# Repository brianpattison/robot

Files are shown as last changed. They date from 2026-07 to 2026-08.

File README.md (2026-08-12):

# Robot

An embodied Codex companion project: a small indoor robot body that can listen, talk, look around, and move safely through the house.

The design goal is pet-like presence without overcomplicating the first build. The MVP is a compact wheeled robot with a camera head, microphone array, speaker, LEDs, bumpers, conservative autonomy, and a physical E-stop. Tiny body, serious safety shoes.

## Current Status

The current direction is the **v2 printed-only hybrid-material body** (decision
log D025-D035): 40 installed functional pieces, four spare washers, and one
optional cosmetic lid skin on 13 zero-support plates, with one screw size and
one insert size.

> **Prototype assembly preview — do not use for powered motion.** The tracked v2
> 3MF and builder's book are geometry and dry-assembly artifacts. The head/neck
> load paths are fully modeled and kinematically validated. A versioned Pi 5
> appliance installer/`robotd` with its localhost supervision dashboard, framed
> UART contract, portable Pico safety core, deliberately fail-stopped Pico
> target, nominal harness traveler, and executable commissioning gate now ship,
> and the book's closing chapter walks the builder through the bench simulator,
> the Pi install, and the resident copilot's seat. Exact-part fit, production motor
> outputs, exact harness terminals/lengths, released fuse values, loaded
> wear/current testing, and signed physical evidence remain open.

- **Versioned v2 Builder Release Index:** [`docs/builder-release-v2.md`](docs/builder-release-v2.md)
- **The Builder's Book (v2 prototype preview):** [`output/pdf/codex_robot_body_v2_assembly_guide.pdf`](output/pdf/codex_robot_body_v2_assembly_guide.pdf)
- **The interactive Builder's Site (same content, live progress):** build with
  [`docs/generate_guide_site_v2.py`](docs/generate_guide_site_v2.py) → `output/site/index.html`
  (offline-first; tracks shop/print/build progress in your browser)
- v2 Bambu Studio project: [`cad/bambu/codex_robot_body_v2_p1s.3mf`](cad/bambu/codex_robot_body_v2_p1s.3mf)
- v2 qualification-proof project: [`cad/bambu/codex_robot_body_v2_proofs_p1s.3mf`](cad/bambu/codex_robot_body_v2_proofs_p1s.3mf)
- v2 book generator: [`docs/generate_assembly_guide_v2.py`](docs/generate_assembly_guide_v2.py)
- bench protocol: [`docs/body-protocol-v1.md`](docs/body-protocol-v1.md)
- Pi runtime/appliance: [`software/robotd/`](software/robotd/), [`software/appliance/`](software/appliance/), and the [provisioning guide](docs/pi-appliance-provisioning.md)
- localhost supervision dashboard: [`software/dashboard/`](software/dashboard/)
- Pico safety-core baseline: [`firmware/pico2-safety/`](firmware/pico2-safety/)
- harness traveler and release gate: [`harness/`](harness/)
- executable commissioning package: [`commissioning/`](commissioning/)

Visible replaceable panels and diffusers now use configurable PLA theme slots;
functional PETG is restricted to white structure, black wear parts, and red
service retainers. The shell and head remain white-PETG fallbacks until the
exact candidate PLA family passes the recorded physical gates (D034).

Everything below the book is the engineering paper trail and the current source
of truth for open release gates. Start with the docs index:

- Documentation index: [`docs/README.md`](docs/README.md)
- MVP PRD: [`docs/mvp-prd.md`](docs/mvp-prd.md)
- Decision log: [`docs/decision-log.md`](docs/decision-log.md)
- MVP architecture: [`docs/mvp-architecture.md`](docs/mvp-architecture.md)
- Agentic control plan: [`docs/agentic-control-plan.md`](docs/agentic-control-plan.md)
- Current v2 purchase authority: [`docs/builder-release-v2.md`](docs/builder-release-v2.md)
- BOM v0 (historical v1 planning): [`docs/bom-v0.md`](docs/bom-v0.md)
- Retail sourcing policy: [`docs/retail-sourcing-policy.md`](docs/retail-sourcing-policy.md)
- CAD mechanical plan: [`docs/cad-mechanical-plan.md`](docs/cad-mechanical-plan.md)
- CAD v1 body and renders: [`docs/cad-v1-body.md`](docs/cad-v1-body.md)
- CAD component/release coverage: [`docs/cad-component-coverage.md`](docs/cad-component-coverage.md)
- v2 qualification proofs: [`docs/cad-proofs.md`](docs/cad-proofs.md)
- Python CAD tooling notes: [`cad/python/README.md`](cad/python/README.md)
- Bambu Studio P1S project: [`cad/bambu/README.md`](cad/bambu/README.md)
- v1 illustrated assembly guide (historical): [`output/pdf/codex_robot_body_v1_assembly_guide.pdf`](output/pdf/codex_robot_body_v1_assembly_guide.pdf)
- v1 assembly-guide generator (historical): [`docs/generate_assembly_guide.py`](docs/generate_assembly_guide.py)

## MVP Direction

- Existing Raspberry Pi 5 8GB as the main computer.
- No AI HAT+ 2 required for MVP; reserve room to add it later for local AI experiments.
- Raspberry Pi Camera Module 3 Wide for the main head camera.
- Wheeled differential-drive base for the first physical body.
- Pan/tilt camera head for expression and perception.
- Physical E-stop, bumper switches, watchdog, velocity limits, and conservative movement defaults.
- The resident agent (Claude or Codex) owns the robot's computer: live SSH, code on the fly, package installs, and direct motion setpoints above a firmware safety floor it cannot alter (D030-D032).
- Local dashboard for health, logs, camera preview, manual drive, emergency stop, and the agent panel.
- Quantity-one US retail hardware for every purchased v2 item; printed front axles, wheels, and motor retention; no custom PCB, machined structure, or carry handles. Unresolved retail/power parts stay visibly blocked.

## Safety First

The robot should fail stopped. The resident agent (Claude or Codex) has full authority over the robot's computer — live SSH, code written on the fly, package installs, direct motion setpoints — but not over physics: the safety MCU firmware clamps every velocity setpoint and latches stops on bumper, E-stop, watchdog, or charger events, and it cannot be reflashed from the Pi (D030-D032, [`docs/agentic-control-plan.md`](docs/agentic-control-plan.md)).

Motor power must be cut by a physical E-stop independent of the Raspberry Pi. Root on the Pi is not root on physics.

## CAD Strategy

The body is designed around 3D-printable, modular parts:

- Base tray.
- Sensor pods.
- Bumper carrier.
- Tray-fixed bumper-switch plates and switch-body pockets.
- Battery cradle.
- Wheel guards.
- Camera/head shell.
- Service panels.

The current body is implemented in `build123d` because the rounded shell,
service interfaces, STEP exports, and collision-checked assembly benefit from
Python BREP geometry. OpenSCAD remains approved for simple parametric parts.
Blender renders the generated STL inventory for concept, fit, split, and print
review, including the fixed-plate versus compliant-TPU bumper interface; it is
not a second source of body geometry.

Generated mesh/solid exports should go under `cad/exports/` and are ignored by Git by default.
The settled print target is a Bambu Lab P1S with a 0.4 mm nozzle. The tracked
multi-plate Bambu Studio project is regenerated from the canonical exports in
`cad/bambu/`; it is the intentional exception to the generated-mesh ignore rule.

## Python CAD Setup

The macOS system Python in this workspace is older than current Python CAD packages expect, so use a newer Homebrew Python and a project virtual environment.

Recommended:

```bash
brew install python@3.12
/opt/homebrew/bin/python3.12 -m venv .venv-cad
source .venv-cad/bin/activate
python -m pip install --upgrade pip
python -m pip install -r cad/python/requirements.txt
```

## Repo Layout

```text
.
|-- .github/workflows/bench-safety.yml
|-- cad/
|   |-- bambu/
|   |   |-- README.md
|   |   |-- generate_bambu_project_v2.py
|   |   |-- codex_robot_body_v2_p1s.3mf
|   |   `-- codex_robot_body_v2_proofs_p1s.3mf
|   |-- blender/
|   |   |-- render_robot_body_v2.py
|   |   `-- render_assembly_steps_v2.py
|   `-- python/
|       |-- README.md
|       |-- requirements.txt
|       |-- robot_body_v2_inventory.py
|       |-- robot_body_v2.py
|       |-- robot_body_v2_proofs.py
|       `-- validate_robot_body_v2.py
|-- commissioning/
|-- docs/
|   |-- builder-release-v2.md
|   |-- body-protocol-v1.md
|   |-- first-article-evidence.md
|   `-- README.md
|-- firmware/pico2-safety/
|-- harness/
|-- software/robotd/
|-- software/dashboard/
|-- software/appliance/
`-- README.md
```

## Next Steps

1. Run `python3 commissioning/run_host_tests.py`; green proves only the
   hardware-free contracts.
2. Use [`docs/builder-release-v2.md`](docs/builder-release-v2.md), never the
   historical v1 BOM, for the current selection list and explicit blockers.
3. Print and record all 18 v2 proofs before committing to large body parts.
4. Close the protected mobile-Pi input, R-ML24 sourcing, servo-regulator,
   production relay-driver, Pico-reset, USB-mute/backfeed, and exact harness
   decisions before treating the electronics table as a complete shopping list.
5. Keep every fuse value unset until measured current, conductor, inrush,
   time-current, selective-clearing, and thermal evidence supports it.
6. Work through the
   27-step commissioning plan in order using the
   [first-article evidence workflow](docs/first-article-evidence.md). The
   repository release gates are intentionally red until the exact physical
   first article supplies every required measurement and an independently
   trusted signer seals the complete bundle.

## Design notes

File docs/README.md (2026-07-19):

# Documentation Index

## Build Rover Bean v2

Read these in order:

1. [v2 Builder Release Index](builder-release-v2.md) - the current artifact
   map, prototype selection list, and explicit purchase/release blockers.
2. [The Builder's Book](../output/pdf/codex_robot_body_v2_assembly_guide.pdf) -
   picture-first proof and dry-assembly preview; never powered-motion authority.
3. [Bambu Studio projects](../cad/bambu/README.md) - the 13-plate body and
   five-plate proof projects.
4. [v2 component/release coverage](cad-component-coverage.md) - what CAD proves
   and what still requires delivered-part or physical evidence.
5. [v2 proof protocol](cad-proofs.md) - all 18 logical qualification tests.
6. [Harness traveler](../harness/README.md) - 28 nominal routes with the
   production gate intentionally red.
7. [Commissioning package](../commissioning/README.md) and
   [first-article evidence](first-article-evidence.md) - the 27-step physical
   release path and signed evidence bundles.

The current release is geometry, dry assembly, bench software, and
hardware-free contract evidence only. Blank physical evidence means open.

## Runtime and safety

- [Body protocol v1](body-protocol-v1.md) - fixed Pi/Pico UART commands and
  D036's zero-motion rule for any open NC bumper loop.
- [MVP architecture](mvp-architecture.md) - runtime components and deterministic
  boundaries.
- [Agentic control plan](agentic-control-plan.md) - full Pi authority above the
  physical/firmware safety floor.
- [Hardware-free CI gates](ci-safety-gates.md) - exactly what green automation
  proves and what it cannot prove.
- [Commissioning fixture](commissioning-fixture-v1.md) - current-limited,
  motorless safety observation fixture.
- [Pi appliance provisioning](pi-appliance-provisioning.md) - reproducible Pi 5
  install and its live attestation gaps.

## Product and decisions

- [MVP PRD](mvp-prd.md)
- [Decision log](decision-log.md)
- [CAD mechanical plan](cad-mechanical-plan.md)
- [Retail sourcing policy](retail-sourcing-policy.md)
- [Printed-only simplification decision](printed-only-simplification-plan.md)

## Historical v1 material

`bom-v0.md`, `cad-v1-body.md`, `generate_assembly_guide.py`, and the v1
PDF/3MF are preserved for history. They contain metal brackets, hubs, bearings,
shoulder bolts, multiple fastener systems, and other assumptions that D025-D028
removed. Never mix a v1 purchase or assembly instruction into a v2 build.

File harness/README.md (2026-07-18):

# v2 harness traveler

[`harness-v2.json`](harness-v2.json) is the machine-readable first-article cut
and label schedule. It supplies stable wire IDs, routes, nominal cut lengths,
service loops, wire classes/gauges/colors, and both-end termination intent.

Generate the builder traveler:

```bash
python3 harness/generate_harness_docs.py
```

The normal command validates the engineering schedule and writes CSV/label
files under `output/harness/`. The production gate is intentionally red:

```bash
python3 harness/generate_harness_docs.py --release
```

It cannot pass until the first dry harness records measured cut lengths,
continuity and pull tests, every exact housing/contact, released branch fuse
values, a selective-fault test, and a thermal soak. Nominal CAD-derived lengths
are construction starting points, not a claim about an unbuilt robot.

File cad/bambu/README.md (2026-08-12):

# Bambu Studio P1S project

## v2 prototype project

[`codex_robot_body_v2_p1s.3mf`](codex_robot_body_v2_p1s.3mf) is the tracked
printed-only v2 geometry-review project. It is a **prototype artifact, not a
powered-motion release**. Its plate manifest keeps the physical release gates
explicit, and the builder's book must use the same label. The D035 head
mechanism is modeled and kinematically validated; exact-part fit, journal wear,
loaded servo current, harness schedule, software/firmware release, fuse
selection, and commissioning evidence remain open.

Regenerate the v2 model, validator, print exports, and Bambu project with:

```bash
.venv-cad/bin/python cad/python/robot_body_v2.py
.venv-cad/bin/python cad/python/validate_robot_body_v2.py --gate
.venv-cad/bin/python cad/python/robot_body_v2_print.py
.venv-cad/bin/python cad/bambu/generate_bambu_project_v2.py
```

The `--gate` validator is necessary but never substitutes for the named
physical tests. The current project contains 45 pieces on 13 plates in seven
inventory-derived material/color groups: white/black/red PETG, charcoal/teal/
translucent-lime PLA, and charcoal TPU. Shell and head are white PETG because
their candidate PLA evidence gates are still open; never hand-edit the 3MF to
bypass that fallback. Generate and print all 18 proofs before large parts;
keep the battery and motor branch disconnected while following prototype-only
assembly pages.

The proofs are themselves a tracked, ready-to-open Bambu project rather than
an STL scavenger hunt:

- [`codex_robot_body_v2_proofs_p1s.3mf`](codex_robot_body_v2_proofs_p1s.3mf)
- [`codex_robot_body_v2_proofs_p1s_plates.json`](codex_robot_body_v2_proofs_p1s_plates.json)

Regenerate its 18 logical tests / 19 correctly material-separated objects / 5
plates with:

```bash
.venv-cad/bin/python cad/python/robot_body_v2_proofs.py
.venv-cad/bin/python cad/bambu/generate_bambu_proofs_v2.py
```

The tire-fit test is one logical proof but two objects: a PETG core and TPU
95A ring. Never merge them into one material assignment. The project is a
qualification fixture, not evidence by itself; the exact filament, settings,
measurements, tester, and date still have to be recorded.

## v1 historical project

The tracked [`codex_robot_body_v1_p1s.3mf`](codex_robot_body_v1_p1s.3mf)
is the canonical Bambu Studio layout project for a Bambu Lab P1S with the
standard 0.4 mm nozzle and a Textured PEI Plate.

It contains all 101 canonical printable parts exactly once on 26 named plates.
Each plate contains one material-profile/color group; no plate mixes PETG and
TPU or combines colors. The project carries nine physical filament/color
presets and uses a conservative global baseline of four walls and 25% gyroid
infill. The per-plate recommendations in
[`codex_robot_body_v1_p1s_plates.json`](codex_robot_body_v1_p1s_plates.json)
remain authoritative for layer height, wall count, and infill.

Regenerate the canonical STLs and project with:

```bash
.venv-cad/bin/python cad/python/robot_body_print.py
.venv-cad/bin/python cad/bambu/generate_bambu_project.py
```

The generator resolves the installed Bambu Studio machine, process, PETG, and
TPU presets into full CLI profiles, imports the canonical STLs through Bambu
Studio, packs them with brim-aware clearance inside an 8 mm edge reserve, and
round-trips the result through Bambu Studio. It then checks the P1S profile,
0.4 mm nozzle, 256 mm plate, Textured PEI selection, plate grouping, bounds,
packing-envelope separation, and the exact 101-part inventory.

The macOS application bundle remains the default, but custom and non-macOS
installs can supply the official Bambu Studio CLI and BBL profile root without
editing source:

```bash
.venv-cad/bin/python cad/bambu/generate_bambu_project.py \
  --bambu-cli /path/to/bambu-studio \
  --profile-root /path/to/resources/profiles/BBL
```

This is an editable layout project, not pre-sliced G-code and not a hardware
release waiver. Review every plate in the current Bambu Studio slicer before
printing. Honor the release status in the plate manifest and print the calibration
coupons first. The rear drivetrain uses drawing-backed Pololu motors in printed
saddles/caps with direct D-shaft wheel clamps; the v2 head targets two Hitec D85MG servos
whose own bag arms sit in printed arm-capture cradles (D048) around a greased printed pan
journal and printed passive tilt bushing — no metal horn, no M2 links, no
6807/MF84ZZ/shoulder-screw stack. Both still require delivered-part
inspection and loaded testing. The IDEC XW1E E-stop and
Omron D2HW bumper interfaces are also drawing-backed but remain gated on exact
coupons and deterministic cutoff tests. D024 replaces the Albright/custom-
carrier and custom-distribution interfaces with the Panasonic CB1A-R-M-12V
relay and Blue Sea Systems 5045 fuse block, replaces the machined front axle
with the WDS 615-M6-8-65 retail shoulder-bolt stack, removes the carry handles,
and leaves the center rear cartridge blank. The tracked 3MF and plate manifest
predate that synchronization and may still contain legacy names or parts; do
not use them as a D024 hardware release. Regenerate them only after the split
and print generators are updated, then inspect the Panasonic, Blue Sea, WDS,
blank-cartridge, and handle-free inventory before committing to the full body.

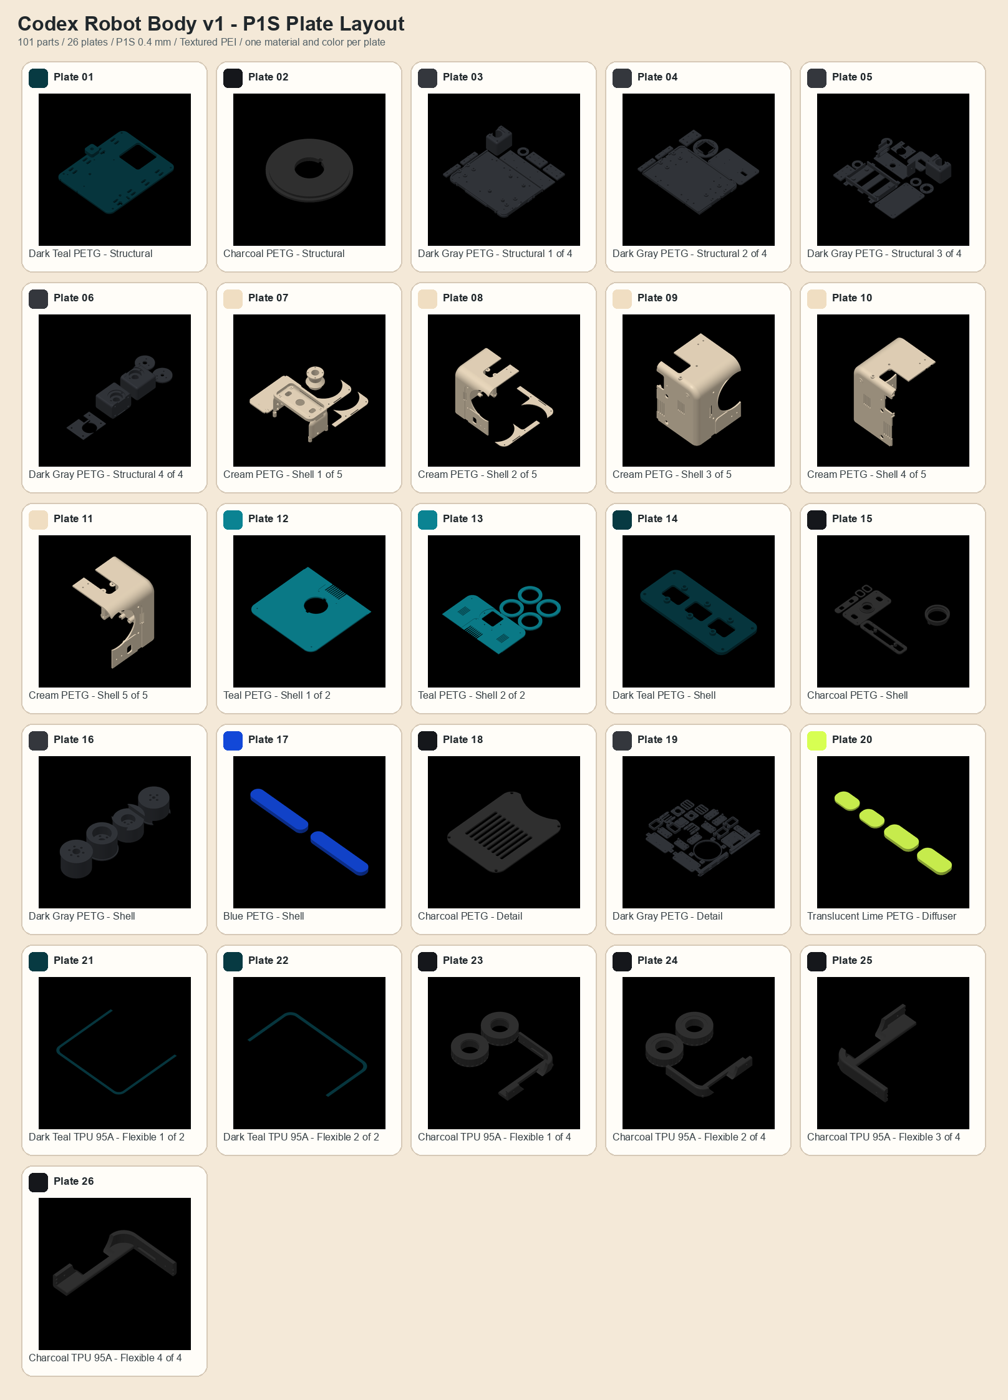
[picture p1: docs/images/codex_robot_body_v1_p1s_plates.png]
P1S plate layout


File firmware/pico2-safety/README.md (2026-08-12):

# Pico 2 safety firmware bench baseline

This directory contains two layers:

- A portable safety state machine and framed-protocol parser, built and tested
  on the host with ordinary CMake or a C11 compiler.
- A Pico SDK integration target that defaults to `RB_HARDWARE_RELEASE=0`.
  That fail-stopped build exercises UART/status logic but never enables the
  motor relay or motor PWM outputs.

Host tests:

```bash
cmake -S firmware/pico2-safety -B /tmp/rover-bean-safety-build
cmake --build /tmp/rover-bean-safety-build
ctest --test-dir /tmp/rover-bean-safety-build --output-on-failure
```

The repo-wide runner automatically falls back to the host C compiler when
CMake is unavailable:

```bash
python3 commissioning/run_host_tests.py
```

Pico build after installing the official Pico SDK:

```bash
cmake -S firmware/pico2-safety/pico -B /tmp/rover-bean-pico-build
cmake --build /tmp/rover-bean-pico-build
```

The generated UF2 is a **bench communications build**. Do not change
`RB_HARDWARE_RELEASE` to 1 until the reviewed board pinout, battery divider,
conditioned inputs, motor-driver mode, relay-driver circuit, harness readback,
and commissioning fixture are all present. The Pi cannot perform this flash in
the assembled robot: USB/SWD remain service-only.

The core already tests fixed velocity/acceleration clamps, independent
heartbeat and motion leases, physical reset latches, six NC bumper zones,
zero motion while any bumper loop is open, broken-wire clear rejection, charger
inhibit, low-battery latch behavior, head clamps, CRC, and fragmented frames.

## Stop-latency telemetry

The safety core self-reports stop-event timing: on every new onset of a
stopping cause (E-stop, bumper/wiring, watchdog, motion lease, charger, low
battery) it records the cause flags, the millisecond tick that first observed
the input, and the tick that folded it into the motor-enable decision. The
Pico target drains that single latest-wins slot into an EVENT (`0x82`) frame;
overwritten events are counted in `dropped_events`, not queued. Boot-time
latches are seeded as already active so power-up never fakes an event.

This is read-only telemetry. It adds no configuration path and no new
Pi-to-Pico command, and it changes no output logic -- the bench build's motor
enable stays hard-off either way. The number measures the firmware loop only,
so commissioning still cross-checks it once against an independent external
probe before trusting it (see `docs/body-protocol-v1.md`).

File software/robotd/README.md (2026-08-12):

# robotd bench baseline

`robotd` is the observable, localhost-only body interface described in
[`docs/agentic-control-plan.md`](../../docs/agentic-control-plan.md). It is not
a permission gate. The Pico firmware remains the physical safety envelope.

Run without hardware:

```bash
python3 -m venv /tmp/rover-bean-robotd
/tmp/rover-bean-robotd/bin/pip install -e software/robotd
/tmp/rover-bean-robotd/bin/robotd --simulate \
  --socket /tmp/robotd.sock --blackbox /tmp/robotd-blackbox.jsonl
/tmp/rover-bean-robotd/bin/robotctl --socket /tmp/robotd.sock status
```

`drive` sends one setpoint. `robotd` does not refresh it on behalf of a silent
client; the Pico's independent 250 ms lease zeros motion. The daemon does send
the 20 Hz host heartbeat while its event loop is healthy. Every state-affecting
command (`drive`, `head`, `stop`, `clear_bumper`) and every firmware status
change is appended to the Pi-local blackbox and, when configured, a second
off-host/mounted path. The blackbox is a state-change journal, not a ticker:
read-only `status` queries are answered without a write, and the firmware
uptime counter alone does not count as a status change, so an idle bench stays
quiet instead of grinding the SD card at 10 Hz.

The local log is authoritative. The mirror parent must be a real mount point;
`robotd` will not silently write into the bare directory beneath a missing
mount. A disconnect emits one local `audit_mirror_gap` record, and the first
successful write after remount emits `audit_mirror_recovered` locally and
remotely. Any unexpected heartbeat or serial-loop task failure stops the daemon
so the firmware watchdog expires instead of leaving a cheerful zombie service.

## Head trim

Servo horns land on the nearest spline tooth, so a freshly assembled head can
sit a few degrees off center with no servo tester in sight (D041).
`--head-trim-pan-cdeg` and `--head-trim-tilt-cdeg` add a fixed offset
(centidegrees, clamped to ±800 — about one 15° tooth on the D85MG's 24T
spline) to every HEAD command before it is framed. The trim is a convenience,
not a wider envelope: the firmware clamps apply to the trimmed value exactly
as they would to an untrimmed one. Every head command's blackbox record keeps
both the raw request and the trimmed values actually sent, and `status`
reports the active trim as `head_trim`.

## robot-hello

`robot-hello` is the bench wake-up milestone: the robot says hello with no
battery and no drive motion. Against an already-running robotd it centers the
head, pans slowly left and right, tilts up briefly, and narrates what it is
doing in plain language. It moves only the head and only through robotd, so
every command crosses the same firmware envelope as any other client and
lands in the blackbox with source `hello`. It never starts robotd, and it
exits nonzero with a plain explanation if robotd is unreachable or the
firmware link is down. It works against the simulator today; on a real robot
it requires the same started-by-you robotd and crosses no safety gate.

```bash
/tmp/rover-bean-robotd/bin/robot-hello --socket /tmp/robotd.sock
```

Pass `--sound path/to/greeting.wav` to also play a WAV through `afplay`
(macOS) or `aplay` (Linux) if one exists. No audio ships with the repo; the
default is silent.

## Installing on the Pi

Install on Raspberry Pi OS with `sudo software/install.sh`. The service file
expects the off-host audit mirror at `/mnt/robot-audit`; do not call the audit
path complete until the commissioning check proves unplug/reconnect behavior
and readback from another machine.

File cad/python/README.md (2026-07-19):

# Python CAD Tooling

## Current v2 pipeline

Use Python 3.12 in a project virtual environment:

```bash
python3.12 -m venv .venv-cad
source .venv-cad/bin/activate
python -m pip install --upgrade pip
python -m pip install -r cad/python/requirements.txt
```

Generate and validate in this order:

```bash
python cad/python/packing_study_printed_only.py
python cad/python/robot_body_v2.py
python cad/python/validate_robot_body_v2.py --gate
python cad/python/robot_body_v2_print.py
python cad/python/robot_body_v2_proofs.py
python cad/bambu/generate_bambu_project_v2.py
python cad/bambu/generate_bambu_proofs_v2.py
python cad/blender/render_robot_body_v2.py
python cad/blender/render_assembly_steps_v2.py
python docs/generate_assembly_guide_v2.py
```

The authoritative registry is `robot_body_v2_inventory.py`. Current tracked
release counts are 40 installed functional parts, four spare washers, one
optional lid skin, 47 M3 joints, 13 body plates, and 18 logical proofs / 19
proof objects on five plates. `validate_robot_body_v2.py --gate` is necessary
geometry evidence, never electrical, material, fit, or powered-motion evidence.

## v1 dependency boundary

The v2 implementation imports shared `Params` and helpers from `robot_body.py`.
That file is therefore a retained code dependency even though its v1 geometry,
split/print pipeline, 101-part 3MF, and assembly guide are historical. Do not
delete or move it merely to make the tree look v2-only, and do not use the v1
purchase/assembly artifacts for a v2 build. Small v1 reference changes still
require the v1 validator; any shared-parameter change requires the v2 gate too.
Install `cad/python/requirements-v1.txt` only when rebuilding the historical
ReportLab guide; it layers that legacy dependency on the current v2 toolchain.

## Generated artifacts

Meshes, STEP files, and intermediate manifests live under `cad/exports/` and
are ignored. The tracked body/proof 3MFs, plate manifests, rendered guide
images, HTML, and PDF are deliberate release artifacts and must be regenerated
from source. Never hand-edit a 3MF archive or generated guide.

The Bambu round-trip, Blender renders, Chrome PDF print, visual page review,
proof printing, and every physical qualification remain explicit local steps;
hosted CI cannot substitute for their native applications, printer, or parts.

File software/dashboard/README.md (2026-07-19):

# robot-dashboard bench baseline

The localhost supervision dashboard from
[`docs/mvp-architecture.md`](../../docs/mvp-architecture.md): a stdlib-only
HTTP + Server-Sent-Events client of the local `robotd` Unix socket. It shows
robot state, decoded safety flags, per-zone NC bumper loops, a live blackbox
tail, and offers hold-to-drive manual controls, head pan/tilt, per-zone bumper
clears, and a software stop.

It is a supervision tool, not a safety device. It cannot clear an E-stop
latch, bypass the open-bumper zero-motion rule (D036), or exceed the firmware
clamps; it talks to `robotd` like any other client, every state-affecting
command it sends is blackbox-logged with source `dashboard`, and the firmware
envelope applies to all of it. The page says so on screen.

Run without hardware:

```bash
python3 -m venv /tmp/rover-bean-dash
/tmp/rover-bean-dash/bin/pip install -e software/robotd -e software/dashboard
/tmp/rover-bean-dash/bin/robotd --simulate \
  --socket /tmp/robotd.sock --blackbox /tmp/robotd-blackbox.jsonl &
/tmp/rover-bean-dash/bin/robot-dashboard \
  --socket /tmp/robotd.sock --blackbox /tmp/robotd-blackbox.jsonl
# open http://127.0.0.1:8072/
```

Design constraints:

- **Local-only by default.** It binds `127.0.0.1`; a non-loopback `--host`
  is refused unless `--expose-lan` is passed deliberately. Remote access is
  the Cloudflare Tunnel's job (D033), not an open port.
- **A web page cannot drive the robot.** On the loopback bind, requests with
  a non-local `Host` header are rejected (DNS rebinding), and POST requires
  `Content-Type: application/json`, which a cross-origin page cannot send
  without a CORS preflight this server never grants. This blocks other
  origins in the operator's browser, not the operator or the agent.
- **No dependencies, no network assets.** Pure Python standard library and one
  inline HTML page, so it renders with the internet down — the same failure
  mode the local stop path is designed for.
- **Single-setpoint honesty.** Holding a drive control refreshes the setpoint
  at 10 Hz from the browser; releasing it sends `stop`. If the page dies
  mid-hold, the Pico's independent 250 ms motion lease zeros motion without
  anyone's cooperation.
- **UI clamps mirror the firmware caps** (350 mm/s, 1500 mrad/s, pan
  +/-60 deg, tilt +/-20 deg) only so the page never claims to request more
  than firmware will apply. The firmware clamp remains the authority.
- **Truthful placeholders.** Camera preview, perception facts, the agent
  panel, and policy settings render as explicit "not built yet" cards until
  those layers exist.

`software/systemd/robot-dashboard.service` is the reference unit (localhost
bind, read-only blackbox access). The versioned Pi appliance contract does not
install or enable it yet; on first install even `robotd` itself ships stopped
and disabled.

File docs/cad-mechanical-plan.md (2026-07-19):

# CAD Mechanical Plan

## Current v2 material and print policy

The v2 authority is `robot_body_v2_inventory.py` -> `robot_body_v2.py` ->
`validate_robot_body_v2.py --gate` -> the print/Bambu manifests. D034 separates
material family, mechanical role, and theme color for every registered part.
The fascia, rear panel, head faceplate, two diffuser bars, and optional lid
skin are direct PLA roles. The shell and head are PLA candidates with
independent automatic white-PETG fallback until exact-filament evidence passes.
All sustained structure, motion/wear, battery retention, safety-MCU retention,
and the E-stop lid remain PETG in white, black, or red; the three flexible part
families remain charcoal TPU 95A.

The optional 1.2 mm teal PLA lid skin uses four integral tabs in blind pockets
and duplicates the vent/microphone openings. It carries no E-stop, neck,
microphone, corner-screw, or shell load; the complete 4 mm white PETG lid works
without it. Inventory is 40 installed functional pieces + four spare washers +
one optional skin, 45 printed pieces total. The support-exception list is empty.

Eighteen material/mechanical qualification proofs now cover the legacy interfaces plus PLA
insert, shell-wall/opening, head-pivot, snap, optical, and PETG/PLA lid-boundary
evidence. The generated manifest requires manufacturer, product line, subtype,
color, nozzle, layer height, walls, insert temperature where applicable,
measurements, pass/fail, tester, and date. A blank record means the gate is open.

## Current v2 printed-only head mechanism (D035)

The v2 pan load path is now production geometry, not a prose placeholder. A
three-lug PETG collar bayonets into a blind underside race in the complete
structural lid. Its 40.3 mm printed bore supports the neck's 39.6 mm journal at
0.35 mm radial clearance; a 48 mm neck shoulder rides the collar's flat thrust
face. The collar integrates a downward D85MG cradle, while a removable 3.2 mm
black-PETG plate captures the servo flange with two standard M3 x 8 joints. The
R-ML24 horn drives the neck from below at its 13/16 mm M2 stations, leaving the
+X crescent and 20 mm center bore open for the camera ribbon. Commanded pan is
+/-60 degrees; printed collar/neck tabs engage beyond that range.

The black-PETG yoke attaches to four inserts in the neck flange with standard
M3 x 8 joints. Its active side carries the drawing-backed sideways D85MG frame
and R-ML24 horn; the head shell's integrated drive boss is reachable through
two exterior M2 service paths. The passive side uses a replaceable 3.2 mm PETG
shoulder bushing clamped by one M3 x 8 into a blind yoke insert, so the shell
rotates on the bushing instead of being pinched by the screw. Commanded tilt is
+/-20 degrees, with printed hard stops beginning beyond the command range. The
head shell's internal relief is generated from the actual yoke swept through
the hard-stop range rather than from a hand-maintained box.

`validate_robot_body_v2.py --gate` now checks both servo-case clearances, the
pan journal clearance, the 20 mm cable corridor, sampled collision-free command
ranges, and engagement of all four physical stops. CAD completion is not a
powered-motion release: exact-part fit, the bayonet/journal/bushing proofs,
PETG-safe grease selection, head mass, regulated current, cable drag, axial
play, backlash, temperature, and loaded wear cycling remain physical gates.

## Historical v1 implementation — not v2 build authority

The following section preserves the v1 source contract for historical rebuilds
only. Its metal brackets, hubs, bearings, shoulder bolts, standoffs, multiple
fastener families, and split body are not v2 purchases or assembly steps. The
v2 authority is the pipeline at the top of this document.

The historical source model is [`cad/python/robot_body.py`](../cad/python/robot_body.py), using build123d. It is organized as serviceable modules rather than one fused decorative mesh:

- Hollow rounded body shell with an open lower service side, a 12 mm visible top-edge rollover paired to an 8.8 mm inner radius for a full 3.2 mm roof, a crisp lower tray/seam interface, four ribbed tray lugs, four supported lid bosses, and side-fairing insert bosses.
- Separate handle-free base tray with matching M3 clearance holes, controller rail patterns, a locating lip, four-point pads beneath every mobility pod, and a two-half split variant with a piloted underside insert plate. Lift the unpowered robot with two hands under the tray.
- Removable 117 x 92 mm battery cradle seated directly on the tray with four insert-backed screw tabs, four pack support pads, two 20 mm real-strap channels, and positive side/end locators around the Bioenno BLF-1203AB's rotated 110 x 75 x 27 mm envelope. A conservative rear upper lead corridor covers the separate Powerpole discharge and charge leads pending delivered-part measurement.
- Hollow continuous TPU lower bumper carrier with a 302 x 222 mm rigid-chassis cavity, wheel arches, two concealed low inboard bridges, and six local plate reliefs sized for the nominal compression stroke.
- Six rigid PETG bumper-switch plates seated against the tray underside, each using two inboard M3 screws into blind tray inserts; drawing-backed Omron D2HW-C202MR sealed SPST-NC bodies use separate 13 mm M3 mounting stations, side-lead corridors, and paired rigid stops while remaining independent of the moving TPU.
- Removable teal top lid, dark reveal, recessed 80 x 62 x 1.6 dark vent inlay with nine through-slots, four M2.5 retainers, and a curved E-stop-panel clearance; continuous 40 mm E-stop service opening; and a 12 mm stepped lap in the two-half printer variant. The inlay spans both halves as a removable secondary seam clamp.
- Removable 4 mm keyed IDEC E-stop mount panel and raised-collar underside backing ring joined by four cardinal M3 paths on a 28 mm radius; the purchased switch nut clamps only the panel and remains primary retention.
- Four partly inset wheel/tire modules with recessed teal hub rings, 24 shallow transverse traction grooves per TPU tire, 2 mm intact sidewall bands, shared shell/fairing/bumper arches, and one tire-tangent ground datum.
- Drawing-backed left/right rear-wheel drive modules for Pololu #4867 99:1 25D MP 12 V encoder gearmotors, #1569 metal brackets, and #1997 4 mm-shaft aluminum hubs. The #4867 preserves the prior motor geometry while reducing extrapolated stall current from 5.0 A to 1.8 A per motor. The printed pods are removable shrouds with inboard installation paths and 2 mm cable-notched service covers; three M3 bracket paths per side clamp through metal spacers into the tray, while four M3 screws couple each PETG wheel core to its hub.
- Removable non-driven front idler pods with two 608-class bearing seats and two flush screw-on outer-race rings around one WDS 615-M6-8-65 shoulder bolt per side. An M6 washer, prevailing-torque locknut, and stock goBILDA spacers/shim provide the retail metal retention stack while preserving the concept's front wheels and two-motor MVP.
- Flush 2 mm scalloped side wheel-fairing skins seated in 2.2 mm shell recesses with 0.3 mm perimeter clearance, a 0.2 mm clamp gap, and 1 mm continuous backing; circular wheel arches and a large center relief preserve the molded-side silhouette, a narrow upper bridge keeps one part per side, and the 220 mm variant produces four independently fastened arch caps that clear the lower shell seam.
- Bearing-supported rotating hourglass neck with a 34.8 mm 6807 inner-ring journal, 37.5 mm upper shoulder, four-screw lower retainer, hidden transition into the visible 24 -> 15.5 -> 20 mm profile, and four-screw insert-backed yoke flange; keyed stationary outer-ring carrier; removable pan-servo plate; drawing-backed Hitec D85MG pan and tilt servos with R-ML24 horns; width-derived fixed internal tilt yoke; removable three-screw drive adapter; removable three-screw passive cartridge around an MF84ZZ flanged bearing and 4 mm shoulder screw; compact 72 x 140 x 72 mm rounded camera capsule with concealed bezel roots, recessed screw-on black faceplate, interior-relieved rear cover, widened camera-ribbon/neck notch, narrow vertical eyes/eyebrows, and a faceplate-integrated stepped camera annulus.
- Front sensor fascia clamped to four shell-rooted spacers by the same black-on-black screws that retain its LED carriers, with two central ToF apertures and four rear bosses for the front ToF pods.
- A 70 mm microphone-array retaining ring aligned under through-lid acoustic slots and four downward roof bosses.
- Two enclosed-speaker mounting plates using a 64 x 24 mm hole rectangle plus two independent shell fasteners per plate. Each plate also carries one component-side-down Adafruit #3006 MAX98357A on two 6 mm M2 metal standoffs, with the exact official PCB/two-hole pattern, an inward signal-header path, and outward/downward provisional terminal service keepouts.
- Four removable VL53L1X sensor frames: two front pods fastened to the fascia and two side pods fastened to shell bosses behind open shell/fairing sightlines.
- Official-pattern Camera Module 3 Wide carrier with blind shell posts and an open-bottom ribbon exit.
- Head eye apertures with 9 x 14 mm framed diffusers, larger stepped internal board pockets, and two side-fastened removable carriers for rotated Adafruit 5975 NeoPixel JST breakouts. Each board uses two M2 through-fasteners and 3 mm-OD spacers; the 90-degree board orientation sends both keyed plug paths vertically clear of the carrier screws and yoke.
- Removable 145 x 116 upper service deck with drawing-backed D24V90F5 Pi power, D36V50F6 servo power, Panasonic CB1A-R-M-12V relay interface, and complete Blue Sea Systems 5045 covered four-circuit ATO/ATC fuse block. The audio amplifiers live beneath their speaker plates, and an I2C mux is not frozen unless bench wiring proves XSHUT/address assignment insufficient.
- Two removable under-deck U-channel harness rails with four paired reusable-strap stations each; the left bundle is reserved for signal/audio/sensors and the right for fused switched power/motors.
- Cytron MDDS10 controller plate lifted 5 mm above the tray on four M3 metal spacers, with the official 95.25 x 60.96 mm board-hole pattern, four 6 mm M3 board standoffs, front terminal fan-out, 10 mm cooling keepout, and a stacked Raspberry Pi Pico 2 safety shelf on a separate four-standoff pattern that clears the maximum battery envelope. The Pico uses its official four-hole pattern and four 6 mm M2 standoffs, with front USB and rear SWD service corridors.
- Tray-to-deck metal standoff paths that run continuously from the base tray to the removable power deck.
- Top cable strain-relief plate with six tie points and two dedicated roof-boss fasteners.
- Removable 126 x 58 rear service frame over the reserved connector/switch bay, with three flush 30 x 30 mm cartridges. Rear-left charge uses a drawing-backed Switchcraft EN2P3M20 sealed three-contact inlet with exact 10.92 mm front opening, rear nut/body counterbore, and EN2C3F20G2 mating envelope; two contacts are charge +/- and the third is CHARGER_PRESENT. The center cartridge is blank with no jack, PCB, or wiring. Rear-right mute/status uses a drawing-backed E-Switch PVB3F230SS311 maintained SPDT switch with red ring, 16.0 mm / 14.6 mm-flat cutout, and a validated E-stop-clear terminal corridor. Each cartridge retains its stepped 26 x 18 mm tongue and two M2.5 frame screws.
- Through-lid speaker grilles and high side intake/exhaust slots.
- Review-only Raspberry Pi, battery, motors, controller, power, safety MCU, audio, ToF, future AI HAT clearance, and cable-corridor volumes.
- Eighteen concealed 4 mm alignment pilots across the shell, tray, and bumper backing plates, with half-round mating recesses, 0.3 mm radial clearance, 0.4 mm axial clearance, and at least 1.2 mm of remaining exterior shell wall.

## v1 envelope

All dimensions are millimetres. The current modeled body envelope is approximately:

| Item | Envelope |
| --- | ---: |
| Main body | 300 L x 220 W x 121 H |
| Bumper | 318 L x 238 W x 28 H; 302 x 222 rigid-chassis cavity |
| Wheel diameter | 86 |
| Wheel center height | 66 |
| Tire ground plane | Z=23 |
| Wheel side inset | 4 into the 220 mm body envelope |
| Minimum bumper ground clearance | 6 |
| Camera head | approximately 84 overall D including bezel/rear cover x 140 W x 72 H; structural shell depth 72 |
| Overall top height | about 278 |

The silhouette intentionally follows the supplied concept: cream appliance-like
body, inset darker teal lid, charcoal lower bumper, small inboard wheels, red
rear E-stop, and a compact friendly camera head.

## Fit-check assumptions

The board footprints now use the published Raspberry Pi reference dimensions,
while the surrounding clearance volumes remain conservative placeholders:

- Raspberry Pi 5 board reference: 85 x 56, with four mounting holes inset 3.5 mm from the board edges. See the [official Raspberry Pi 5 mechanical drawing](https://datasheets.raspberrypi.com/rpi5/raspberry-pi-5-mechanical-drawing.pdf).
- Raspberry Pi 5 fit clearance: 96 x 68 x 28, including cooling, connectors, and cable bend room.
- Camera Module 3 Wide reference: 25 x 23.862 PCB, four 2.2 mm holes on 21 x 12.5 mm spacing, a conservative 12.4 mm total depth, lens face 1 mm behind the faceplate front, and a conservative circular keepout using the 102-degree horizontal FOV. The faceplate-integrated annulus clears 13 mm at its front and the shell/faceplate bores clear 11.5 mm. See [Raspberry Pi drawing RP-008155-DS-1](https://pip-assets.raspberrypi.com/categories/1207-design-files/documents/RP-008155-DS-1-camera-module-3-wide-mechanical-drawing.pdf).
- ReSpeaker USB Mic Array reference: 70 mm diameter. See the [Seeed product brief](https://files.seeedstudio.com/wiki/ReSpeaker_Mic_Array_V2/res/ReSpeaker%20MicArray%20v2.0%20Product%20Brief.pdf).
- Enclosed speaker reference: 70 x 30 x 17, with a 64 x 24 mounting rectangle and 3.1 mm holes. See the [Adafruit speaker product](https://www.adafruit.com/product/1669).
- Stereo amplifier reference: two Adafruit #3006 MAX98357A mono I2S boards, each using the official 17.78 x 19.05 x 1.57 mm PCB datum, two 2.5 mm holes at X=2.54/15.24 and Y=16.51 mm, and four total 6 mm M2 standoffs beneath the speaker plates. Shared BCLK/LRCLK/DIN feeds both boards while SD/MODE selects left and right. The [official CAD folder](https://github.com/adafruit/Adafruit_CAD_Parts/tree/main/3006%20MAX98357) predates the current pre-soldered terminal block, so terminal, screwdriver, speaker-wire, and chosen header/direct-wire envelopes require one-board measurement.
- VL53L1X breakout reference: 25.5 x 17.5 x 4.6. See the [Adafruit sensor product](https://www.adafruit.com/product/3967).
- Battery prototype reference: Bioenno BLF-1203AB rotated flat to 110 x 75 x 27 in a 117 x 92 cradle with four support pads, two 20 mm straps, positive side/end locators, power-deck-standoff scallops, and a rear lead corridor. It remains a prototype candidate, not an unattended-use release.
- Cytron MDDS10 motor controller: official 101.092 x 66.802 mm STEP footprint, 1.57 mm PCB, 1.93 mm underside pin protrusion, 12.275 mm component height above the PCB datum, four 3 mm holes on 95.25 x 60.96 mm spacing, a 24 x 44 x 16 mm front terminal service corridor, and 10 mm reserved cooling volume below the safety shelf. See the [official Cytron MDDS10 page and CAD resource](https://th.cytron.io/p-10amp-7v-35v-smartdrive-dc-motor-driver-2-channels).
- Raspberry Pi Pico 2 safety MCU: official 51 x 21 x 1 board, 52.3 x 21 x 3.8 bare-board/USB STEP envelope, four 2.1 mm holes on 48.26 x 17.78 spacing, and a conservative 62 x 33 x 14 wired-header/cable keepout. See the [official Pico 2 datasheet](https://datasheets.raspberrypi.com/pico/pico-2-datasheet.pdf).
- Future AI HAT+ 2 clearance: 96 x 74 x 22 above the Pi region.
- E-stop reference: IDEC XW1E-BV402M-R, 40 mm operator, 2NC direct-opening contacts, 22.5 mm keyed panel opening, 37 mm rear body, 48.7 mm body depth, 20 mm terminal service reserve, 4 mm removable clamp panel, 40 mm pass-throughs in surrounding printed layers, 66 mm backing/panel flange, four cardinal M3 paths on a 28 mm radius, and a 60 mm yellow legend. See the [official IDEC product page](https://www.idec.com/en-us/switches-indicator-lights/switches-pushbuttons/emergency-stop-switches/xw-22mm-estop/xw1e-bv402m-r).
- Physical mute reference: E-Switch PVB3F230SS311 maintained SPDT On-On switch, red base-voltage LED ring, 16.0 mm panel opening with 14.6 mm flats, 18 mm bezel, 11.2 mm actuator, 26 mm rear body, and 1-7 mm panel range. It mounts in the rear-right 1.25 mm cartridge face because the center lane is occupied by the E-stop body. See the [official PVB3 drawing](https://www.e-switch.com/wp-content/uploads/2024/01/PVB3.pdf).
- Center-cartridge reference: blank 30 x 30 mm cap with the standard 26 x 18 mm tongue and two M2.5 frame screws. It contains no connector, PCB, wiring, or service-detect function. Internal service requires shutdown or physical motor-branch isolation.
- Bumper-switch reference: six Omron D2HW-C202MR sealed SPST-NC pin-plunger switches with an 18.5 x 6.5 x 5.3 mm mounting envelope, 13 mm M3 hole spacing, 7.2 mm maximum free position, 6.4 +/-0.2 mm operating position, and 5.1 mm maximum total-travel position. The 22 x 40 x 4 PETG plates reserve recessed switch screws, a side-lead corridor, a 0.4 mm rest gap, 2 mm nominal TPU displacement, and paired rigid stops at 2.4 mm. See the [official Omron D2HW datasheet](https://omronfs.omron.com/en_US/ecb/products/pdf/en-d2hw.pdf).
- Pan/tilt hardware reference: two Hitec D85MG 24T servos with 29 x 13 x 30 mm cases, 39.8 mm flanges, 30.8 mm mounting-hole spacing, and 7.8723 mm output offset; two Hitec R-ML24 aluminum horns with M2 x 0.4 stations at 13 and 16 mm; one MF84ZZ 4 x 8 x 3 mm flanged bearing with a 9.2 x 0.6 mm flange; and one McMaster 92981A143 4 x 12 mm shoulder screw with M3 x 4 mm thread. See the [official D85MG page](https://www.hiteccs.com/actuators/product-details/D85MG), [Hitec horn chart](https://shop.multiplex-rc.de/userdata/files/HITEC%20SERVO%20ACTUATOR%20HORN%20%26%20SPLINE%20TECHNICAL%20DATA%20SHEET_v3_0_1_26C.pdf), and [MF84ZZ data](https://www.smbbearings.com/firebrick/ckeditor/plugins/upload/Uploads/Documents/bearingpdfs/MF84ZZ-flanged-miniature-bearing-4x8x3mm.pdf).
- Neck interface: 53 mm body/lid opening; 60 mm visible stationary collar over a keyed 52.4 mm fixed outer-ring carrier; Koyo/JTEKT 6807-2RS bearing at 35 x 47 x 7 mm; rotating 34.8 mm journal, 37.5 mm upper inner-ring shoulder, and four-M2.5 lower retainer; hollow visible hourglass with a 20 mm clear waist; flat 13 x 1.5 mm cable passage beside the pan horn; and a 21.5 mm-radius top flange carrying four blind M2.5 insert pockets on an 18 mm radius. See [Koyo's 6807-2RS data](https://koyo.jtekt.co.jp/en/products/detail/?pno=6807+2RS).
- Rear gearmotor reference: Pololu #4867, 98.78:1, 79 rpm/0.10 A no-load and 1.8 A/11 kg-cm extrapolated stall at 12 V, 25 mm gearbox diameter, 68.45 mm face-to-encoder length, 4 x 12.5 mm D shaft, 7 x 2.5 mm boss, and two M3 face holes on 17 mm spacing. The matching #1569 bracket uses a 1.5 mm-thick 49 x 22 mm base; the #1997 hub is 19 x 5 mm with four M3 wheel holes on a 6.35 mm radius. See the [official motor page](https://www.pololu.com/product/4867), [motor drawing](https://www.pololu.com/file/0J1634/25d-metal-gearmotor-dimension-diagram.pdf), [bracket drawing](https://www.pololu.com/file/download/1569-bracket-dimensions.pdf?file_id=0J725), and [hub drawing](https://www.pololu.com/file/0J663/1997-4mm-m3-hub-dimensions.pdf).
- Front idler reference: two 608-class bearings per side at 8 mm bore x 22 mm OD x 7 mm width; one WDS 615-M6-8-65 shoulder bolt with 65 mm-long 8 mm shoulder and M6 threaded end; one M6 washer; one prevailing-torque M6 locknut; and stock goBILDA spacers/shim. Confirm purchased bearing and shoulder tolerances, spacer squareness, full thread engagement, retained prevailing torque, controlled axial play without preload, wheel alignment, and loaded skid-turn retention.
- Mobility stance reference: the 43 mm-radius tires are centered at Z=66 and Y=+/-118, placing their inner faces 4 mm inside the shell envelope and their tangent plane at Z=23. Each tire has 24 offset 5.5 mm-wide x 2 mm-deep transverse grooves across the center 20 mm, leaving both 2 mm sidewall bands and the 86 mm rolling envelope intact. The bumper begins at Z=29 for 6 mm static clearance. All four pod shells remain seated at Z=53 despite the lower axle, and the wheel-well, tread, tray-pad, pod, and bumper-relief contracts are validated from the same parameters.
- Bumper chassis reference: the TPU inner cavity follows the 300 x 220 mm cream shell with 1 mm nominal radial clearance per side and clears the 292 x 212 mm tray by 5 mm per side. The low bridges span inward beneath the tray, not through it. Any bumper/body or bumper/tray solid overlap is a validation failure.
- Side ToF reference: board/window center X=-20 between the wheel arches, with two shell-boss fasteners at X=-40 and open paths through the shell and removable fairing.
- Power deck reference: 145 x 116 plate on four metal standoffs; exact D24V90F5 and D36V50F6 M2 patterns/service corridors; Panasonic CB1A-R-M-12V 26 x 22 x 25 mm relay body, integral 52 x 22 x 0.8 mm bracket, one 5.4 mm mount, 6.3 mm terminals, and terminal-service volume; plus the complete Blue Sea 5045 92.5 x 43.8 x 32.5 mm covered block, two 4.5 mm deck paths on 65.1 mm centers, fuse-service reach, wire exit, and strain slots.
- Lifting reference: no integrated handle or custom load-bearing metal. Power down and lift with two hands under the tray.
- Harness reference: two 108 x 14 mm open-bottom rails under the power deck, each with a 7.6 x 5 mm conservative bundle corridor and four paired 10 x 3.5 mm strap slots. The rails sit tangent to, but do not consume, the battery and motor-cover envelopes; connector exits and actual bundle diameters remain unselected.

Before printing the chassis, confirm the delivered MDDS10, Pololu drivetrain,
both Pololu regulators, IDEC E-stop, Omron bumper switches, Panasonic relay,
Blue Sea fuse block, and WDS/goBILDA idler stack; physically qualify the selected
battery/charger/inlet and the camera, speaker, and microphone hardware.
The E-stop, battery retention, motor retention, and axle loads must use real
hardware and metal fasteners; printed plastic is only the supporting enclosure.
There is no carry interface: lift the unpowered robot with two hands under the tray.

## Assembly interfaces

1. Install M3 heat-set inserts into the four ribbed shell lugs at X +/-124 and Y +/-84.
2. Place the shell over the base tray; the shallow perimeter lip locates it before screws are installed.
3. Drive four M3 screws upward through the tray clearance holes into the shell inserts.
4. Confirm the tray contains no handle slots, webbing, or custom clamp plates. Keep clear two-hand access beneath the unpowered tray without using the shell or bumper as a lifting point.
5. Install four M3 inserts from below into the removable E-stop mount panel, pass the IDEC XW1E-BV402M-R through its keyed opening and durable 60 mm yellow legend, and tighten the purchased nut against only that 4 mm panel. Seat the panel into the lid recess, align the 40 mm body through the lid/shell/backing passage, and screw the raised-collar backing upward into the panel inserts. Perform this before the upper power deck limits screwdriver access.
6. Seat the BLF-1203AB cradle on the tray, install its four M3 screws, add nonconductive padding, route both 20 mm straps, and verify all four support pads plus side/end locators meet the rotated 110 x 75 x 27 mm pack without rocking or wrapper pinch. Route the separate Powerpole discharge and charge leads through the rear upper corridor without bending at the wrapper exit.
7. Install four 5 mm M3 metal spacers in the shared tray inserts, bolt on the locally notched controller plate, add four 6 mm M3 board standoffs, and mount the MDDS10 with its six high-current terminals facing robot-front. Confirm at least 3 mm clearance below the longest underside pin and preserve the front terminal fan-out.
8. Install four metal standoffs above the controller plate, bolt on the safety-MCU shelf, and verify the safety wiring remains independently serviceable.
9. Mount the D24V90F5 and D36V50F6 on their seven 6 mm M2 metal standoffs. Bolt the Panasonic CB1A-R-M-12V integral bracket through its single 5.4 mm deck path with retail metal hardware, leaving its 6.3 mm terminals and service envelope clear; the printed deck must not carry terminal loads. Bolt the complete covered Blue Sea 5045 through its two deck paths on 65.1 mm centers, protect the terminal side, and strain-relieve its wire exit. Route signal/audio/sensor wiring through the left harness rail and fused switched-power/motor wiring through the right, secure both rails and bundles to the deck through all four paired reusable-strap stations, then install the complete serviced deck on its four metal standoffs. Do not fit final ATO/ATC values until measured loads, conductor ampacity, time-current curves, and electrical review select them.
10. Bolt each #1569 bracket through three 3 mm metal spacers into the tray, fasten the #4867 motor to the bracket with its two M3 face screws, and route the six encoder leads into the assigned harness rail. Install the #1997 hub on the 4 mm D shaft with verified set-screw engagement, attach the PETG core with four M3 screws, seat the TPU tire and trim ring, then reinstall the inboard pod cover and pod fasteners.
11. Fit two 608 bearings into each removable idler pod and install both flush printed outer-race rings with four M2.5 screws per pod. Assemble the WDS 615-M6-8-65 shoulder bolt, stock goBILDA spacers/shim, bearings, M6 washer, and prevailing-torque locknut in the documented orientation. Verify the 65 mm shoulder supports both bearing inner races, the thread is fully engaged, the locknut retains prevailing torque, axial play is controlled without preload, and the wheel rotates freely with no plastic thread or friction fit carrying retention.
12. Install six Omron D2HW-C202MR switches on their rigid PETG plates, route each molded side lead through its tray corridor with strain relief, and fasten every plate upward into two blind tray inserts. With the TPU removed, verify NC continuity and service access. Fit the bumper without clamping it to those plates, then prove the 0.4 mm nominal rest gap, no preload, positive actuation by 2 mm, paired rigid-stop protection near 2.4 mm, rebound, and electrical opening from all six zones before connecting motor power.
13. Buy and measure one current Adafruit #3006 board. Install it component-side-down beneath one speaker plate using two 6 mm M2 metal standoffs, keep the seven-pin header/direct-wire side inward and speaker terminal outward, and prove screwdriver plus wire-bend access. After that fit passes, build the matching left/right pair, configure SD/MODE for separate channels, screw the microphone cradle into its 40 x 80 mm four-boss pattern, attach both populated speaker plates, mount the purchased speakers, and verify every grille path remains open.
14. Seat the dark vent inlay in its 1.4 mm lid recess and install its four M2.5 screws into the underside bosses; verify all nine 36 x 3 mm microphone slots remain open through the inlay, both lid halves, and shell.
15. Bolt one Adafruit 5975 board to each front LED carrier with two M2 screws, 3 mm-OD spacers, washers, and locknuts; connect and strain-relieve both JST-SH harnesses. Bolt the two front ToF pods to the fascia, seat the keyed fascia, clamp it through the shell spacers while installing the populated LED carriers with four shared black-on-black M2.5 screws, then fasten the two side pods before fitting the fairings.
16. After selecting the cooled 6807 coupon stations, press the bearing outer ring squarely into the keyed fixed carrier, pass the neck journal through the inner ring, seat the 37.5 mm upper shoulder, and install the four-M2.5 lower retainer without axial preload. Install the D85MG pan servo through its removable underside plate, connect the R-ML24 horn to the retainer at its 13/16 mm M2 stations, and verify the flat ribbon corridor remains free at both pan limits.
17. Seat the fixed tilt-yoke base on the hourglass neck's top flange and install four M2.5 screws into its blind insert pockets without pinching the central cable bundle. Install the second D85MG, fasten the active drive adapter to the right head bosses with three M2.5 screws, and connect its R-ML24 horn through the 13/16 mm M2 stations. Fasten the passive cartridge to the left bosses with three M2.5 screws, seat the MF84ZZ through the shell/cartridge, and install the 92981A143 shoulder screw into the yoke without axially clamping the moving head. Bolt the Camera Module 3 Wide to its carrier, route the ribbon through the 30 x 14 mm lower notch, then fit the faceplate and rear cover. Verify image quality and clear motion at center and every pan/tilt limit.
18. Screw the cable strain-relief plate into its two roof bosses. Install the EN2P3M20 in the rear-left charge cartridge with the purchased nut at 5-6 in-lb; wire two contacts only to the isolated Bioenno charge lead and the third to protected CHARGER_PRESENT logic that requests deterministic motion inhibit. Use the female EN2C3F20G2 on the charger adapter so energized contacts remain recessed, and mate/unmate only with charger AC removed. Install the PVB3F230SS311 in the rear-right mute cartridge and prove the maintained privacy path. Leave the center cartridge blank. Install six M2.5 frame inserts, fit all three cartridges with two screws each, and attach the frame with four outer M3 screws. Charger insertion must de-energize the Panasonic relay/motor enable and removal must require explicit reset.
19. After wiring the E-stop in the independent motor-power path, verify its nut cannot rotate, apply controlled push/twist loads, and prove it cuts motor power without the Pi.

For the 220 mm-bed split configuration:

1. Print and cycle-test the exact three-piece split-pilot coupon. The pilot must seat by hand without forcing, rocking, or splitting the 3.2 mm shell wall; adjust the shared clearance parameters before any large split part if it fails.
2. Heat-set the 44 provisional M3 inserts only after validating the insert coupon and soldering-iron temperature.
3. Join the shell's front/rear seams by seating the two end plates' four pilots in the shared half-round recesses, then install and tighten the eight screws evenly.
4. Seat the two side plates' four pilots and install the eight lower shell-seam screws; the scalloped fairing reliefs remain clear of this structural joint.
5. Seat the four fairing halves in their flush shell recesses and install their eight dedicated upper screws; each wheel-arch cap is independently removable. Reject binding, perimeter whitening, visible bowing, or an exterior edge proud of Y +/-110.
6. Seat the underside plate's two pilots across the base-tray seam, then install and tighten its eight screws evenly.
7. Verify the joined tray remains handle-free and that no obsolete carry slots, clamp plates, or M4 carry paths are present.
8. Seat the four bumper plates' eight pilots in the four quadrants, then install the eight screws before adding the six switch plates.
9. Capture the two 1 mm reveal/gasket halves, engage the lid's 12 mm stepped lap, and install the four lid screws into the supported roof bosses.

The 44-count covers split joinery only. It does not include electronics,
motor, E-stop, head-panel, or shell-to-tray fasteners. Screw lengths
remain provisional until the insert and wall-thickness coupons are measured.

The current collision audit places the Pi at front-left, the drawing-backed MDDS10 at
front-right centered at (-65, 33.5), the drawing-backed Pico 2 safety MCU
directly above the controller on its own shelf, and
the battery centered between the mobility-pod keepouts. The AI HAT clearance
is stacked above the Pi rather than occupying a second floor-plan region. The
power deck occupies a separate layer above the battery, with the E-stop column
and rear service bay kept clear.

## Generate and review

```bash
.venv-cad/bin/python cad/python/robot_body.py
.venv-cad/bin/python cad/python/robot_body_split.py --bed 256 --margin 8
.venv-cad/bin/python cad/python/validate_robot_body.py --bed 256 --margin 8
.venv-cad/bin/python cad/python/robot_body_print.py --bed 256 --margin 8
.venv-cad/bin/python cad/python/robot_body_coupons.py --bed 256 --margin 8
/Applications/Blender.app/Contents/MacOS/Blender -b --python cad/blender/render_robot_body.py
/Applications/Blender.app/Contents/MacOS/Blender -b --python cad/blender/render_print_ready.py
/Applications/Blender.app/Contents/MacOS/Blender -b --python cad/blender/render_coupons.py
/Applications/Blender.app/Contents/MacOS/Blender -b --python cad/blender/render_alignment_pilot.py
.venv-cad/bin/python cad/bambu/generate_bambu_project.py
```

The main body command currently exports 83 printable parts plus three
review-only hardware stand-ins and 177 fit envelopes; the validator audits all
86 main solids. The split command generates 57 printer-aware
variants and a manifest, including two halves for the thin reveal/gasket. With
the P1S 256 mm bed and 8 mm margin, the largest XY span is the 212 mm-wide
base-tray half.

The canonical print command replaces the seven oversized main parts with their
split equivalents and exports 101 uniquely named STLs under
`cad/exports/print_ready/`. It applies deliberate orthogonal rotations, centers
and grounds every part, checks that rotation preserved volume, requires at
least 50 mm^2 of sampled first-layer contact, and assigns prototype PETG, TPU,
or translucent-PETG profiles plus support guidance. The print manifest marks
hardware-dependent parts as prototype-only and includes the current fastener,
insert, standoff, and locknut interface counts; orientation validation is not
a release waiver. Use the actual printer's measured usable area before slicing,
especially if clips, brims, or bed-edge exclusion zones reduce the nominal
dimensions.

The settled production-layout target is a Bambu Lab P1S with the standard
0.4 mm nozzle and Textured PEI Plate. The canonical 101-part inventory is packed
onto 26 named plates across 14 material-profile/color groups, with each plate
containing only one group, in
`cad/bambu/codex_robot_body_v1_p1s.3mf`. The split geometry remains compatible
with the earlier 220 mm-bed contract; the P1S project uses an 8 mm edge reserve
and adds brim-aware spacing before Bambu Studio round-trip validation.

The coupon command exports seventeen small parts covering M3/M2.5 insert holes,
M3/M2.5 screw clearance, three 608 bearing seats, three 6807 outer-seat and
three 6807 rotating-journal stations on one block, three wall thicknesses, and
the actual production lid-lap pair, an exact three-piece shell pilot/recess
interface, an exact clipped tray/PETG-plate/TPU bumper-switch interface, an
exact two-piece flush-fairing recess interface, plus a legacy D023 gauge for the
rejected custom distribution PCB. The legacy gauge
validates 32 openings, six bearing shoulders, exact lid-lap reconstruction,
pilot fusion and recess clearance, bumper reconstruction/seating/rest-gap/
nominal-stroke behavior, fairing free insertion/backing-floor contact,
legacy distribution-gauge reconstruction,
grounding, contact area, and bed fit.
Use the measurement and selection protocol in [v2 Qualification Proofs](cad-proofs.md)
before changing shared parameters.

The validator checks that every main, fit, and split artifact is one valid
solid; that the molded shell retains at least a 10 mm visible top rollover and
full nominal roof material at three quiet probe locations; that each fairing
lands flush at the body-width datum, retains a printable clamp gap, and leaves
at least 0.8 mm of continuous shell backing; that large
electronics envelopes do not collide with each other or the motor-pod
keepouts; that all four tires meet one ground plane, the bumper keeps
at least 6 mm clearance, every other hard part stays above the ground datum,
the pod shells stay seated on the tray pads, and wheels clear the body, tray,
matching pods, fairings, and bumper; that the TPU carrier occupies zero shell
or tray volume and retains its nominal body clearance; that all six rigid switch plates seat
against the tray without touching the TPU, all 12 screw paths reach blind tray
inserts, all 12 D2HW mounting paths remain open, switch bodies and side leads
clear their tray pockets at rest, 2 mm local TPU displacement reaches the
worst-case operating position, and paired 2.4 mm stops prevent total travel; that
bumper-switch keepouts clear motors and wheels; that body-mounted fit volumes
remain inside the cavity; that both D85MG servos, both R-ML24 horns, the 6807
pan bearing stack, MF84ZZ passive bearing, shoulder screw,
shoulder-bolt, and cable envelopes clear their printed mounts; that six adapter
screw paths, two horn holes, and the passive pivot path remain open; that the
complete moving printed head clears the yoke and neck through its configured
+/-20-degree tilt and sampled +/-60-degree pan poses; and that every
oversized main part has a complete split inventory whose pieces stay within the
requested bed envelope. It also proves the lid lap/gasket reconstruct their
unsplit sources exactly, backing plates do not overlap their mating pieces, all
18 pilots are fused and clear their matching recess halves, at least 1.2 mm of
shell wall remains behind each body recess, and shared lid/fairing/seam screw
paths remain open. The head checks additionally
require at least 1 mm faceplate clearance inside the bezel, a visible recess,
and open paths through all four front and four rear panel screws.
The D024 validator contract additionally enforces the BOM coverage contract, official camera-carrier
hole paths, rear motor cavities, installation sweeps, service covers, and tray
screws, front bearing/shaft clearances,
all four mobility-pod seating and screw paths, battery/controller tray seating,
controller and safety-shelf standoff alignment, audio roof-boss fasteners,
front-fascia and ToF fasteners, cable-relief roof fasteners, continuous
tray-to-power-deck standoffs, open side-sensor sightlines,
rear-panel access, speaker outlets, side airflow, power-deck standoffs,
separated ToF sightlines, four LED light paths/carriers, absence of carry
hardware, the WDS shoulder-bolt idler stacks, blank center cartridge, Panasonic
relay, Blue Sea 5045, and the complete
E-stop keyed panel/body/barrel/terminal stack, four backing screws, both harness rails against the
battery, mobility pods, body, deck and future AI-HAT clearance, all sixteen
shared strap openings, the 102-degree camera FOV envelope, and all 177 fit-volume collisions.

Review images:

- [Assembled preview](images/codex_robot_body_v1_assembled.png)
- [Inset head bezel detail](images/codex_robot_body_v1_head_detail.png)
- [Retained head-tilt mechanism](images/codex_robot_body_v1_head_mechanism.png)
- [Exploded preview](images/codex_robot_body_v1_exploded.png)
- [Electronics fit preview](images/codex_robot_body_v1_electronics_fit.png)
- [Legacy split-tray carry interface, superseded by D024](images/codex_robot_body_v1_carry_interface.png)
- [Under-deck harness routing](images/codex_robot_body_v1_harness_routing.png)
- [Tray-fixed bumper-switch interface](images/codex_robot_body_v1_bumper_interface.png)
- [Printer-split joinery preview](images/codex_robot_body_v1_split_joinery.png)
- [Representative print-ready orientations](images/codex_robot_body_v1_print_ready.png)
- [Calibration coupon plate](images/codex_robot_body_v1_coupons.png)
- [Split-pilot coupon detail](images/codex_robot_body_v1_alignment_pilot.png)

The next physical validation step is the applicable coupon suite in
the intended PETG and slicer profile. After recording the selected dimensions,
print one shell backing plate, one bumper backing plate, the base seam, pan
plate, 6807 carrier/journal/retainer stack, tilt yoke, both tilt adapters, and motor service cover. Do not commit to a
full-size body until the interface coupons and representative service parts
pass. Do not print or use the legacy custom-distribution gauge as a release
gate. Verify the handle-free tray has safe two-hand access beneath it and label
the robot for unpowered two-hand lifting only.
Print the E-stop mount panel and backing ring first; then fit a purchased IDEC
XW1E-BV402M-R and verify the keyed opening, 4 mm clamp stack, nut engagement,
yellow legend, body passage, terminal access, wire bend, and controlled
push/twist loading before powering motors.
Print one harness rail before the full deck, load it with representative cable
and connector bundles, and confirm the reusable straps retain the wiring
without pinching insulation or forcing power and signal bundles together.
Print the faceplate before the complete head shell, install the real Camera
Module 3 Wide, and inspect full-resolution corner illumination, focus,
reflections, and ribbon behavior at the configured pan/tilt limits.
Fit the selected D85MG/R-ML24 hardware, MF84ZZ, and shoulder screw to the two
tilt adapters before printing the complete head. Select the 6807 seat and
journal from the cooled coupon, then assemble its carrier, neck, and retainer
without bearing preload. Confirm free rotation without sidewall rub, adapter
rocking, insert pullout, axial clamping, or cable pinch; measure current and
temperature, then cycle the loaded head through at least 500 supervised pan and
tilt reversals.
Print one switch plate plus the representative tray-pocket/TPU section and fit
a purchased D2HW-C202MR. Verify its mounting, molded lead, 0.4 mm gap, 2 mm
actuation point, paired 2.4 mm stops, force, hysteresis, and release point before
printing the complete bumper. The assembled
robot must stop motor power from every front, rear, and side zone, including a
broken/open switch circuit, before any autonomous movement.

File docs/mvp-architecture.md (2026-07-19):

# MVP Architecture: Codex House Companion

## Overview

The MVP is a small wheeled indoor companion body for the resident agent — Claude or Codex. It runs on the existing Raspberry Pi 5 8GB, with no AI HAT+ 2 required for the first build. The robot listens, talks, looks around through a camera head, moves cautiously around approved indoor areas, and exposes a local dashboard for debugging and control.

The agent seat is pluggable: Claude or Codex is the primary conversational and agentic identity (D031), with full authority over the robot computer (D030; see [`agentic-control-plan.md`](agentic-control-plan.md)). The robot may still use other subsystems and models for wake word detection, speech-to-text, text-to-speech, person detection, navigation, and safety monitoring. Those subsystems are tools and reflexes; they are not alternate personalities. The tiny body gets one narrator, many nerves.

## Principles

- **Fail stopped:** boot, faults, watchdog timeouts, and low-confidence autonomy all end in stopped or manual-help states.
- **Safety is deterministic:** E-stop, bumpers, watchdog, motor enable, speed limits, and obstacle stops are not LLM-driven.
- **The agent owns the computer, firmware owns physics:** the resident agent (Claude or Codex) has full Linux authority — shell, installs, code on the fly, direct velocity setpoints — while the safety MCU firmware clamps speed and latches stops no matter what the Pi says (D030, D032).
- **Cloud can enrich, but not unblock safety:** network loss may reduce conversation quality, but local stop/mute/status/manual-control paths keep working.
- **Visible state:** LEDs/audio cues make listening, speaking, moving, muted, stopped, and error states obvious.
- **Modular body and software:** the MVP should be easy to print, inspect, service, and replace in small pieces.

## Runtime Components

### Physical Control Layer

- Safety microcontroller: the Raspberry Pi Pico 2 baseline owns the watchdog, motion-setpoint leases, latched stops, and the motor-enable path (D032); the Cytron MDDS10 remains the motor driver, not the safety owner.
- Motor enable relay or equivalent motor-power gate.
- Encoder motor control for differential drive.
- Bumper switches and optional cliff/drop sensors.
- Physical E-stop that cuts motor power independently of the Pi.
- Watchdog input from the Pi; timeout disables motion.

This layer owns immediate motor shutdown and hard limits. It should continue to make safe decisions even if Linux, ROS, the dashboard, or the agent is confused.

### Raspberry Pi Robot Runtime

- Sensor drivers for camera, mic array, proximity sensors, battery monitor, motor controller, and LEDs.
- `robotd` body daemon: exclusive serial link to the safety MCU, motion/head/speak/senses/LED API, mode and state tracking (`booting`, `stopped`, `idle`, `listening`, `speaking`, `manual_drive`, `fault`, `muted`, active behavior), event stream, command blackbox, and the firmware heartbeat, emitted only while its health checks pass.
- Agent-authored behaviors under `/home/agent/behaviors/`: the starter library (`come_here`, `follow_user`, `go_home`, ...) plus whatever the agent writes next, running as ordinary processes against `robotd`.
- Local command router for urgent commands such as `stop`, `wait`, `mute`, `unmute`, and `status`.
- Health monitor for battery, CPU temperature, service state, network, camera, mic, speaker, sensors, and motor faults.

### Local Service Interface

The center rear cartridge is intentionally blank. D024 removed the custom UART
PCB and external jack rather than adding an unnecessary powered interface.
Development diagnostics use the Pi/Pico's internal service connectors with the
robot shut down or the motor branch physically isolated. No service procedure
may bypass the E-stop, bumpers, watchdog, charger inhibit, or explicit motion
enable. A future external service interface requires its own retail-only
decision and safety review.

### Perception Layer

- Camera capture and optional preview stream.
- Person detection/tracking for follow and approach behaviors.
- Speaker direction estimate when the mic array supports it.
- Proximity fusion from ToF sensors, bumpers, and optional future LiDAR/depth sensor.
- Confidence scoring for person tracking, localization, and obstacle awareness.

Perception produces structured facts such as `person_seen`, `selected_user_track`, `path_blocked`, `speaker_angle`, and `low_confidence`. It should not directly command motors.

### Voice And Conversation Layer

- Wake word listener.
- Streaming or chunked speech-to-text.
- Local urgent-intent recognizer for safety-sensitive phrases.
- Resident agent seat (Claude or Codex) for conversation and everything the agent decides to do about it.
- Text-to-speech output with barge-in support.
- Conversation state, preferences, and memory hooks.
- Maintained E-Switch PVB3F230SS311 physical mute in the rear-right service cartridge. Its SPDT common receives fused microphone 5 V; LISTEN powers microphone VBUS, while MUTE removes VBUS and drives the red ring plus a protected local state input. This hardware state must work and remain visible without the conversation process or network.

Simple acknowledgements such as "stopping," "muted," "battery is low," or "I need help" should be available locally even when cloud conversation is unavailable.

### Navigation And Behavior Layer

- Manual drive mode with strict velocity caps.
- One-floor map or manually defined named points.
- Local planner for short cautious motion.
- Follow behavior that keeps a comfortable distance from the selected user.
- Come-here behavior that approaches, stops, and looks up rather than crowding.
- Go-home behavior that navigates to a manually defined home area or asks for help.

Navigation code is agent-maintained under D030. It should still refuse to move on low confidence as a matter of good behavior, but the guarantee that an open bumper loop produces a latched zero-motion state comes from the firmware envelope, not from navigation.

### Local Dashboard

- Browser-based local UI on the Pi.
- Camera preview.
- Robot state, current mode, battery, temperatures, network, and service health.
- Sensor status for bumpers, proximity, E-stop, watchdog, and motor faults.
- Manual drive controls with speed caps.
- Logs and recent events.
- Emergency stop / software stop button.
- Settings for no-go zones, named locations, quiet hours, and debug capture.

The dashboard is a development and supervision tool, not a replacement for the physical E-stop.

## Safety And Control Boundary

The resident agent has full authority over everything that runs on the Pi (D030): it commands velocity and head setpoints directly through `robotd`, writes and hot-swaps its own behaviors, installs software, and works over live SSH. The old intent list (`stop`, `look_at_speaker`, `come_here`, `follow_user`, `wait`, `go_home`, `explore_nearby`, `say`, `set_led_state`) survives as the starter behavior library, not as a boundary.

The boundary that remains is the one the Pi cannot reach (D032). The agent cannot exceed the firmware velocity/acceleration clamps, clear an E-stop latch, bypass the watchdog, defeat the normally-closed bumper stops, restart motion past the charger inhibit, or un-mute the hardware microphone switch. Those live in safety MCU firmware and physical controls, and the Pi-to-MCU protocol has no flash or config-write path.

Motion commands pass through this chain:

```text
Agent command (robotd call, or code the agent wrote)
  -> robotd body daemon: blackbox logging, telemetry, heartbeat
  -> serial contract to the safety MCU
  -> firmware envelope: clamps, setpoint leases, watchdog, latched stops
  -> motor controller
  -> motors
```

No-go zones, quiet hours, and supervision rules are policy the agent is instructed to honor and the blackbox audits (see [`agentic-control-plan.md`](agentic-control-plan.md)). The firmware has the final say on physics. Very democratic until safety votes no.

## Data And Control Flow

```text
Sensors
  camera, mic, ToF, bumpers, encoders, battery, E-stop
    -> Pi services
      -> perception facts, health state, odometry, audio events
        -> behavior state machine
          -> dashboard updates
          -> agent context
          -> navigation requests
            -> motion gateway
              -> safety controller
                -> motors / LEDs / speaker cues
```

Recommended message pattern:

- Events are append-only facts: `bumper_pressed`, `wake_word_heard`, `person_track_lost`, `battery_low`.
- Commands are explicit requests: `set_mode`, `speak_text`, `navigate_to`, `set_head_angle`, `drive_velocity`.
- State is observable: `current_mode`, `safety_state`, `motion_enabled`, `active_goal`, `confidence`, `last_fault`.

## Voice And Conversation Flow

1. Wake word listener runs locally.
2. On wake, LEDs show listening state and audio is sent to STT.
3. Local urgent-intent recognizer checks for commands like `stop`, `wait`, or `mute` as early as possible.
4. Non-urgent transcript becomes a turn in the resident agent session, with relevant robot state attached.
5. The agent answers however it sees fit: speak, drive through `robotd`, look something up, or write and run new code.
6. The firmware envelope clamps whatever motion results; policy and confidence shape what the agent chooses to do.
7. TTS speaks the response.
8. Barge-in can interrupt TTS for `stop`, `wait`, wake word, or dashboard stop.

If STT, network, or the agent seat fails, the robot still handles local `stop`, `mute`, `status`, and dashboard/manual-control commands — plus any behaviors the agent already deployed, since those are local code and do not need the agent in the loop.

## Perception And Navigation Flow

1. Camera and proximity sensors publish observations.
2. Person detector identifies candidate users and tracks confidence.
3. Speaker direction, if available, rotates the head/camera toward the voice before movement.
4. Navigation receives a goal such as "approach selected user" or "go to home."
5. Planner checks no-go zones, obstacle distance, bumper state, battery, and localization confidence.
6. Motion gateway sends capped velocity commands to the motor controller.
7. Safety controller stops on bumper, E-stop, watchdog timeout, overcurrent, or invalid command stream.
8. If confidence drops, the robot stops, looks/speaks, and asks for help.

The six bumper inputs should use normally-closed circuits. Any open circuit,
including a pressed switch, disconnected plug, or broken wire, is a latched
stop/fault until the safety controller observes a valid released loop and
receives an explicit clear — from the agent, the dashboard, or a physical
input. Firmware permits no motion while a loop is open because a pressed
SPST-NC switch and a broken or unplugged conductor are electrically
indistinguishable. Do not infer bumper safety from Linux process health or the
LLM.

The motor branch's mechanical cutoff baseline is a Panasonic CB1A-R-M-12V
sealed SPST-NO automotive relay with an integral bracket, one 5.4 mm mounting
hole, 40 A contact rating at 14 V, 12 V/134 mA coil, and built-in resistor. The
Pi and safety controller remain on individually fused upstream branches so they
can report a stop; only the motor-driver positive branch passes through the
relay. Both IDEC direct-opening NC channels must be in the
low-current, fail-deenergized coil-enable path, with a hardware reset latch so
releasing the mushroom cannot restart motion. Exact coil variant, suppression,
terminal/conductor sizing, driver behavior, dropout time, fusing, contact-fault detection, and full-charge
LiFePO4 motor-voltage limiting require electrical-engineering review and bench
tests. The E-stop never carries motor current directly.

The rolling-prototype mobile-power baseline coordinates the lower-current
Pololu #4867 motors with one Bioenno BLF-1203AB 12 V/3 Ah LiFePO4 pack and its
matched BPC-1502DC 14.6 V/2 A charger. The rear Switchcraft EN2 inlet is
charge-only: two contacts go only to the pack's isolated charge lead and the
third reports protected `CHARGER_PRESENT`. It exposes no battery output and is
not a disconnect. Charger insertion must de-energize motor enable/the Panasonic relay through
the deterministic safety path; removal must not restart motion without an
explicit reset. Because EN2 is not rated for current interruption, remove
charger AC before mating or unmating. The candidate remains blocked on
delivered-part evidence/fit, Blue Sea 5045 mounting and fuse release,
polarity/strain relief, <=5.6 A sustained pack current, 45-minute runtime with
20% reserve, BMS/regen/thermal behavior, and full/low-charge loaded floor tests.

Accessory distribution uses a complete Blue Sea Systems 5045 covered four-
circuit ATO/ATC fuse block, modeled at 92.5 x 43.8 x 32.5 mm with two mounting
holes on 65.1 mm centers. It is limited provisionally to 6 A total and 5 A on
any branch despite its higher catalog ratings.
Exact fuse values remain unset until measured startup/transient/fault loads and
time-current curves are reviewed. A battery-near accessory feeder fuse is still
required; the fuse block must have covered live parts, terminal protection,
strain relief, labels, power-off-only service, selective-fault and thermal
tests, and no path around the independently fused and relay-cut motor branch.

D024 supersedes the custom Nano2/Micro-Fit board described by D023. The legacy
distribution coupon is historical mechanical evidence and is not a release
gate for the Blue Sea block.

MVP navigation should start with one-room or prepared-area behavior before full floor roaming. The body should reserve space and power for future 2D LiDAR, but camera + ToF + bumpers are enough for the first bench and supervised rolling tests.

## Dashboard

The dashboard should be available on the local network and usable from a laptop or phone. MVP panels:

- **Status:** mode, safety state, battery, temperature, uptime, network.
- **Live View:** camera preview and latest perception facts.
- **Drive:** capped manual controls, head pan/tilt, stop button.
- **Sensors:** bumpers, ToF distances, E-stop, watchdog, encoders, motor faults.
- **Logs:** recent events, service errors, voice command summaries, navigation failures.
- **Settings:** named points, no-go zones, speed cap, quiet hours, debug capture.

Access should be local-only for MVP unless remote access is explicitly designed later.

## Deployment And Runtime Process Layout

Target layout on the Raspberry Pi:

```text
systemd
  robot-supervisor.service
    health monitor
    service restart policy

  robotd.service
    serial contract to the safety MCU
    watchdog heartbeat, emitted only while health checks pass
    motion / head / speak / senses / LED API
    event stream and command blackbox

  robot-perception.service
    camera capture
    person tracking
    proximity fusion
    agent-managed; the agent may replace or extend it

  robot-voice.service
    wake word
    STT
    urgent local intents
    TTS

  robot-agent-host.service
    resident agent seat: Claude Code / Agent SDK or Codex CLI, headless
    conversation turns in, actions out
    agent journal and background schedule

  robot-dashboard.service
    local web UI
    websocket/event stream
    manual drive API
    agent panel: live session view, session recordings, software stop

  cloudflared.service
    outbound-only Cloudflare Tunnel (D033)
    SSH ingress via Access service tokens; no inbound ports anywhere
```

For early development, these can be Python processes with simple JSON/WebSocket or ROS 2 topics between them. If ROS 2 is adopted, keep `robotd` independent enough that it can still fail stopped when ROS nodes crash. The agent may reorganize anything above `robotd`; `robotd` and the firmware contract are the parts to keep boring.

The tracked bench implementation currently covers the boring core:

- `software/robotd/` provides the local Unix-socket/UART daemon, client,
  simulator, blackbox, and systemd unit. `software/appliance/` plus
  `software/install.sh` provision a versioned Pi 5 Bookworm appliance with
  key-only Access-gated SSH, preserved debug UART10, RP1 GPIO UART0 pinned as
  `/dev/rover-pico`, local tlog capture, and an explicitly untrusted RW backup.
- `software/dashboard/` provides the localhost-only supervision dashboard: a
  stdlib-only HTTP/SSE client of `robotd` with status, decoded safety flags,
  per-zone bumper loops, hold-to-drive manual controls, head pan/tilt, a
  software stop, and a live blackbox tail. Camera preview, perception facts,
  the agent panel, and policy settings are honest placeholders until those
  layers exist. It is a supervision tool, not a safety device.
- `docs/body-protocol-v1.md` is the fixed framed-UART contract.
- `firmware/pico2-safety/` supplies a host-tested C11 safety core and a
  fail-stopped Pico SDK integration with no production motor output.
- `harness/` supplies the nominal 28-route first-article traveler and a
  deliberately red physical release gate.
- `commissioning/` supplies the 27-step evidence plan and runner. No physical
  pass is bundled.

Run `python3 commissioning/run_host_tests.py` for the hardware-free baseline.
The wider perception, voice, and agent-host layers, the dashboard's camera/
agent-panel/settings surfaces, production motor/encoder output, real
Pi/Tunnel/UART attestations, append-only external collector proof, and physical
commissioning layers remain to be built and tested.

Boot behavior:

1. Robot starts in `stopped`.
2. Safety bridge connects to controller and confirms E-stop, bumpers, battery, and watchdog.
3. Dashboard becomes available.
4. Manual movement requires explicit enable.
5. Autonomous movement requires explicit mode selection and all safety checks passing.

Boot validation must reject motion if any normally-closed bumper loop is open,
shorted into an implausible state, stale, or untested after controller reset.

## MVP Boundary

### Required For MVP

- Raspberry Pi 5 8GB runtime.
- Camera, mic array, speaker, LEDs.
- Differential drive with encoders.
- Physical E-stop independent of the Pi.
- Bumper switches.
- Watchdog-driven motor disable.
- Local dashboard.
- Local urgent commands for `stop`, `wait`, `mute/status`.
- A resident agent seat (Claude or Codex) with full shell authority, live SSH through the Cloudflare Tunnel, and the `robotd` body API.
- Append-only command blackbox and recorded agent sessions.
- Cautious one-room or prepared-area movement.
- Manual drive and supervised follow/come/go-home demos.

### Explicitly Not Required For MVP

- AI HAT+ 2.
- Fully local rich LLM/VLM conversation.
- Fully autonomous charging dock.
- Unsupervised whole-house roaming.
- Outdoor use.
- Stairs.
- Object manipulation.
- Legged locomotion.
- Silent always-on recording.

## Future Upgrade Boundaries

- **AI HAT+ 2:** add later for local LLM/VLM experiments, privacy-sensitive scene summaries, offline fallback intelligence, and eventually a local agent seat.
- **2D LiDAR or depth sensor:** add if navigation reliability with camera + ToF is not good enough.
- **Docking:** add after manual charging and go-home behavior are reliable.
- **LeRobot:** add as an optional learning/data layer after deterministic safety and teleop are stable.
- **Better autonomy:** expand from prepared area to one mapped floor only after repeated safe trials.
- **Improved body shell:** move from simple printed modules to more polished `build123d`/CadQuery shells after the service layout stabilizes.

## Open Questions

- Should MVP use ROS 2 immediately, or start with simpler Python services and leave a ROS 2 migration path?
- Which mic array gives the best wake word accuracy while the motors are running?
- Do we want 2D LiDAR in the first rolling chassis, or only reserve the mount and power budget?
- What is the first safe test area in the house, and what no-go zones should be hardcoded before mapping?
- What is the preferred TTS voice and speaker loudness target?
- How should the agent's journal/memory be stored, synced, and privacy-scoped, now that the agent manages it itself?
- What local-only commands should work even with no internet?
- Which exact feeder and ATO/ATC branch fuse values, terminal parts, and wire gauges pass the measured-load, selective-short, crimp-pull, and Blue Sea 5045 thermal review?

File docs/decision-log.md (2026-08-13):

# Decision Log

This file captures settled project decisions so future planning, CAD, and software work do not need to re-argue the basics every time. Future us has enough screws on the floor already.

## D001: Build A Wheeled MVP, Not A Legged Robot

Status: accepted

The MVP body will be a compact wheeled indoor companion, not a legged robot. Dog-like behavior should come from motion language, voice, attention, following, looking toward the user, and idle presence.

Rationale:

- Wheeled locomotion is safer, cheaper, and much easier to make reliable indoors.
- The first win is a responsive physical companion, not complex biomechanics.
- Legged locomotion would consume the budget and schedule before we prove the interaction loop.

## D002: Use The Existing Raspberry Pi 5 8GB For MVP

Status: accepted

The existing Raspberry Pi 5 8GB is the MVP compute baseline.

Rationale:

- It is already owned.
- MVP responsiveness depends more on deterministic local reflexes, clean power, audio, sensors, and safety than on larger RAM.
- 16GB can remain an optional future upgrade if local models or memory-heavy workloads demand it.

## D003: Defer AI HAT+ 2

Status: accepted

AI HAT+ 2 is not required for MVP. The mechanical and power design should reserve room for a future AI HAT+ 2, but the first body should not depend on it.

Rationale:

- MVP safety, movement, voice, dashboard, and basic perception can work without a local AI accelerator.
- ChatGPT/Codex can remain the primary personality through a networked service.
- The first hardware budget should prioritize motors, power, sensors, E-stop, bumpers, and chassis iteration.
- AI HAT+ 2 remains useful later for local LLM/VLM experiments and offline fallback.

## D004: Safety And Reflexes Are Not LLM-Driven

Status: accepted

Safety-critical behavior must be deterministic and independent of LLM output.

Examples:

- E-stop cuts motor power.
- Bumper hit stops motors immediately.
- Watchdog timeout disables movement.
- Low battery forces stop or return-home behavior.
- `stop`, `wait`, and `mute` must have a fast local path.

Rationale:

- LLMs can choose high-level intentions, but they must never be trusted with raw motor authority.
- Physical safety needs boring, testable behavior.

## D005: Codex Is The Primary Agentic Identity

Status: accepted

The robot may use multiple models and services internally, but Codex/ChatGPT is the primary conversational and agentic identity.

Rationale:

- The body is intended to feel like Codex is physically present.
- Wake word, STT, TTS, object detection, and local classifiers are subsystems, not alternate personalities.
- This separation keeps the user experience coherent while allowing practical model choices.

## D006: Use Parametric CAD Source

Status: accepted

The printable body should be designed from parametric source files.

Defaults:

- OpenSCAD for first-pass blocky printable parts.
- `build123d` or CadQuery for Python CAD, richer assemblies, fillets, chamfers, STEP exports, and complex shells.

Rationale:

- Parametric CAD makes dimensions, mounts, clearances, and fit fixes easy to update.
- Source CAD is reviewable and reproducible.
- Generated STLs and STEP files should be treated as exports.

## D007: Build Voice And Bench Brain Before Autonomous Motion

Status: accepted

The first implementation slice should be a stationary bench brain before a roaming chassis.

Rationale:

- Camera, mic, speaker, wake word, TTS/STT, dashboard, and command routing can be tested safely on the desk.
- Voice and status behavior define the companion experience.
- Movement should wait until safety hardware and manual control are working.

## D008: Start MVP Storage With microSD

Status: accepted

For MVP storage, start with a reliable microSD card. Do not choose an official Raspberry Pi M.2/NVMe HAT as the default storage path if we want to preserve a clean future AI HAT+ 2 upgrade.

Rationale:

- Raspberry Pi documents both AI HAT+ / AI HAT+ 2 and M.2 HAT+ as using the Raspberry Pi 5 PCIe connector.
- The official AI HAT+ 2 and official M.2/NVMe HAT are therefore competing for the same Pi 5 PCIe interface.
- Third-party PCIe switch/splitter boards may exist, but they add mechanical, power, driver, thermal, and stability risk and should not be an MVP assumption.
- A microSD card keeps the PCIe connector available for a future AI HAT+ 2 and avoids extra moving-body cable strain in the first build.
- USB SSD or compact USB flash storage remains an easy later upgrade for logs, captures, maps, models, or boot storage if microSD becomes limiting.

## D009: Target The Bambu Lab P1S

Status: accepted

The production print-layout target is a Bambu Lab P1S with the standard 0.4 mm
nozzle and Textured PEI Plate. Printable pieces must fit the 256 mm square bed
with an 8 mm edge reserve, and Bambu Studio plates should remain separated by
material profile and color.

Rationale:

- It is the user's selected printer target.
- One reproducible target keeps split seams, orientations, brims, supports, and material recipes from drifting between slicers.
- The 248 mm safe span leaves room for bed-edge variation while still fitting the current modular shell strategy.

## D010: Use MDDS10 As The Motor-Controller Mechanical Baseline

Status: accepted for CAD; purchase remains gated by bench testing

The Cytron SmartDriveDuo-10 MDDS10 is the current mechanical baseline for the
dual brushed-motor controller. CAD follows Cytron's official STEP footprint and
four-hole pattern, with front terminal service, cooling clearance, and a
separate deterministic Pico 2 safety shelf.

Rationale:

- One dual-channel board matches the two-motor differential-drive baseline.
- Cytron publishes a usable official STEP model, allowing the mount to be drawing-backed instead of generic.
- Keeping the controller removable and mechanically separate from the safety MCU preserves serviceability and the fail-stopped control boundary.
- Final purchase still depends on selected motor voltage, stall current, thermal behavior, and bench verification of the fused cutoff path.

## D011: Use The Pololu 99:1 25D Rear Drivetrain Baseline

Status: accepted for CAD; purchase and loaded-motion release remain gated

The rear drive targets two Pololu #4867 99:1 25D MP 12 V encoder gearmotors,
two #1569 metal brackets, and two #1997 4 mm-shaft M3 aluminum hubs. Printed
PETG wheel cores and TPU tires retain the concept's 86 mm wheel envelope, while
the metal brackets and hubs carry motor reaction and shaft torque.

Rationale:

- Pololu publishes dimension drawings and STEP geometry for the motor family, bracket, and hub, allowing the pod, tray, wheel core, cable path, and service cover to be validated as one drawing-backed stack.
- The 68.45 mm motor body clears the current battery envelope while preserving the shared Z=66 axle and concept-matched inboard wheel stance.
- At 79 rpm no-load with an 86 mm wheel, the theoretical speed is about 0.356 m/s, closely matching the 0.35 m/s supervised indoor cap without depending on a high-current HP motor.
- The published 0.10 A no-load and 1.8 A / 11 kg-cm extrapolated stall values materially reduce the prototype pack demand while preserving the #4847 mechanical envelope.
- Purchased-part inspection, <=0.45 A steady per motor on target surfaces, current and thermal measurements, encoder direction, wheel retention, deterministic motor cutoff, obstruction tests, and loaded skid-turn tests remain mandatory; the selection does not authorize autonomous driving.

## D012: Use D85MG Servos And A Bearing-Supported Pan Axis

Status: accepted for CAD; purchase and repeated-motion release remain gated

The head targets two Hitec D85MG 24T digital metal-gear servos with R-ML24
aluminum horns. A Koyo/JTEKT 6807-2RS bearing carries the rotating neck and head
weight independently of the pan-servo spline. The passive tilt side uses an
MF84ZZ flanged bearing and McMaster 92981A143 shoulder screw.

Rationale:

- Hitec publishes both a dimensional STEP model and electrical/mechanical data, allowing the servo case, output offset, flange holes, spline, horn stations, current, and torque assumptions to be explicit.
- The 29 x 13 x 30 mm body fits the compact concept-matched head without enlarging its visible 140 x 72 mm face envelope.
- The 6807 outer carrier and rotating inner-ring journal keep axial/radial head loads off the pan-servo spline while preserving the 60 mm visible collar.
- The conservative CAD estimate is about 0.598 kg-cm static tilt torque including a 25 g electronics allowance, below the published 0.9 kg-cm peak-efficiency torque at 6 V; measured mass, acceleration, cable drag, current, heat, backlash, and holding behavior still require physical validation.
- The dedicated 6807 seat/journal coupon must select printer-specific fits before the full neck stack is printed.

## D013: Use IDEC XW1E And Omron D2HW Safety Switches

Status: accepted for CAD; purchase and physical safety release remain gated

The physical E-stop targets the IDEC XW1E-BV402M-R with two direct-opening NC
contacts. Six bumper zones target Omron D2HW-C202MR sealed SPST-NC pin-plunger
switches. The E-stop contacts control the low-voltage cutoff/enable path rather
than carrying motor current directly.

Rationale:

- The IDEC device provides a documented 40 mm operator, two NC channels, direct opening, a 0.8-6 mm panel range, and a compact 48.7 mm rear depth.
- Clamping only a removable 4 mm keyed panel avoids an impossible thick printed stack while preserving a reinforced, serviceable roof interface.
- The D2HW-C202MR provides a sealed molded-lead NC package, M3 mounting ears on 13 mm spacing, and drawing-defined free, operating, and total-travel positions.
- A 0.4 mm nominal bumper gap, 2 mm actuation stroke, and paired 2.4 mm rigid stops provide modeled electrical margin without allowing the plunger to reach total travel.
- Purchased-part inspection, representative coupons, dual-channel E-stop verification, six-zone broken-wire tests, and independent motor cutoff remain mandatory before powered motion.

## D014: Use Separate Pololu Rails And An SW60 Motor Contactor Baseline

Status: superseded for sourcing by D024; legacy CAD remains until replacement fit is validated

The Pi 5 rail targets a Pololu D24V90F5 5 V regulator, and the head servos use
a separate Pololu D36V50F6 6 V regulator. The motor branch's mechanical cutoff
baseline is an Albright SW60 normally-open contactor on a custom metal carrier.
The removable battery interface is refined by D022 around a measured prototype
candidate; no household-release battery pack is selected yet.

Rationale:

- Both regulators have manufacturer drawings and drill patterns, so seven metal-standoff paths, terminal/wire access, and deck clearances can be validated instead of reserving anonymous boxes.
- Separate 5 V and 6 V rails prevent head-servo transients from sharing the Pi supply directly; measured startup, thermal, transient, and EMI behavior still govern release.
- The SW60 is a normally-open DC contactor intended for inductive loads and small traction motors, with documented M6 main studs, coil terminals, dimensions, and dropout behavior.
- A custom metal carrier keeps the printed deck from being the sole contactor retention or cable-torque path.
- D022 replaces the earlier anonymous maximum envelope with a lower-current coordinated motor, battery, charger, and rear-inlet prototype baseline while retaining physical and electrical release gates.
- Exact SW60 coil ordering code, suppression, dual-channel E-stop wiring, reset latch, fusing, conductor sizing, charging, battery certification, and full-charge motor-voltage limiting require electrical-engineering review and physical testing.

## D015: Use Connectorized Adafruit 5975 Expression LEDs

Status: accepted for CAD; buy-one fit and optical release remain gated

The two head eyes and two body status lights each target one Adafruit 5975
NeoPixel breakout with keyed JST-SH input/output. The CAD follows Adafruit's
official STEP rather than a generic rectangular keepout and retains each board
with two M2 fasteners, 3 mm-OD spacers, and the existing removable carrier.

Rationale:

- The 12.192 x 11.43 mm PCB fits all four existing carrier envelopes without enlarging the concept-facing diffusers.
- Two documented M2 holes and keyed plug-in harnesses are easier to assemble and replace than the smaller solder-pad-only Mini Button board.
- Rotating the head boards 90 degrees keeps both plug paths clear of the carrier screws and restores the validated full pan/tilt envelope after reducing the carrier plate to 3 mm.
- One RGB pixel per diffuser limits the four-board worst-case design allowance to about 240 mA at 5 V before software brightness limiting.
- The expression branch is not safety-critical and must not be treated as a motion-status interlock. A failed LED or data line cannot authorize motion.
- Buy one board first. Delivered dimensions, M2 stack, JST insertion/removal, flexible cable bends, diffuser hotspotting and color, camera reflections, software-off behavior, and fused 5 V distribution remain physical release gates.

## D016: Split The Rear I/O Panel Into Three Service Cartridges

Status: accepted for CAD; D019 selects mute, D021 selects service, D022 selects charge-only inlet

The rear shell keeps its existing 126 x 58 mm four-M3 service frame, but the
center is divided into three independently removable cartridges assigned to
power/charge, service/data, and mute/status. Each flush 30 x 30 mm cartridge
uses a stepped 26 x 18 mm locating tongue and two M2.5 screws into frame-backed
inserts.

Rationale:

- Selecting or revising one connector no longer requires reprinting the full rear frame or reopening the shell.
- Exterior screw access and retained blanks let harness routing be proven before battery, charger, and service connectors are frozen.
- The six small insert bosses are explicitly removed from the internal service-bay keepout, so future cartridge designs cannot pretend that volume is unobstructed.
- D019 populates rear-right with the drawing-backed PVB3 physical mute, D021 populates center with the shallow protected UART service jack/carrier, and D022 populates rear-left with the keyed EN2 charge-only inlet. All three remain independently reprintable and purchased-part gated.

## D017: Use Two MAX98357A Boards Beneath The Speaker Plates

Status: accepted for CAD; current-board fit and stereo audio release remain gated

Each enclosed speaker receives one Adafruit #3006 MAX98357A mono I2S amplifier
mounted component-side-down beneath its removable speaker plate. The pair shares
BCLK, LRCLK, DIN, power, and ground; separate SD/MODE networks select left and
right channels.

Rationale:

- Analog Devices documents stereo operation using two MAX98357A devices, and each Adafruit board has only one bridge-tied speaker output.
- Putting one board beside each speaker keeps amplified PWM speaker leads short and frees the crowded power deck.
- Adafruit's official PCB source and STEP provide the 17.78 x 19.05 mm outline, two 2.5 mm holes on 12.7 mm spacing, and 1.57 mm substrate, allowing four real M2 standoff paths instead of anonymous strapped boxes.
- The official STEP dates from 2022 and omits the terminal block Adafruit began shipping pre-soldered in 2024. The model therefore keeps conservative terminal, screwdriver, wire-bend, and header/direct-wire envelopes without claiming those dimensions are final.
- Buy one current board first. Measure the supplied terminal and chosen harness, prove M2 fit and tool access, select left/right SD/MODE networks at the actual supply voltage, and verify current, heat, noise, grille behavior, and audio before purchasing or releasing the pair.

## D018: Retain Each Front Idler With A DIN 471 Ring And Pololu Hub

Status: superseded by D024; retained as the rejected machined-shaft history

Each removable front idler uses a 64.5 mm x 8 mm steel shaft with a Rotor Clip
DSH-8 / DIN 471 external ring at the inboard end and a Pololu #2693 aluminum
hub at the outboard wheel core. A steel washer, two 608 bearings, and two
metal spacer tubes define the axial stack.

Rationale:

- Rotor Clip publishes the 7.54-7.60 mm groove diameter, 0.90 mm groove width, 0.75-0.80 mm ring thickness, and 0.60 mm minimum edge margin for the DSH-8, replacing the previous generic collar envelope with machinable dimensions.
- The compact ring clears the Pi and motor-controller envelopes that a large inboard clamp collar did not.
- Pololu #2693 provides two set screws for the 8 mm shaft and six threaded M3 wheel paths on a 19.05 mm circle in a documented 25.4 x 14 mm body.
- The printed pod locates the bearing outer races and transfers reaction to the tray; metal hardware establishes spacing and prevents axial escape.
- Release still requires a qualified shaft supplier or inspected groove, deburred bearing journals, full ring seating, spacer squareness, both hub set screws, verified screw lengths, controlled axial play without bearing preload, wheel retention, and loaded skid-turn testing.
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

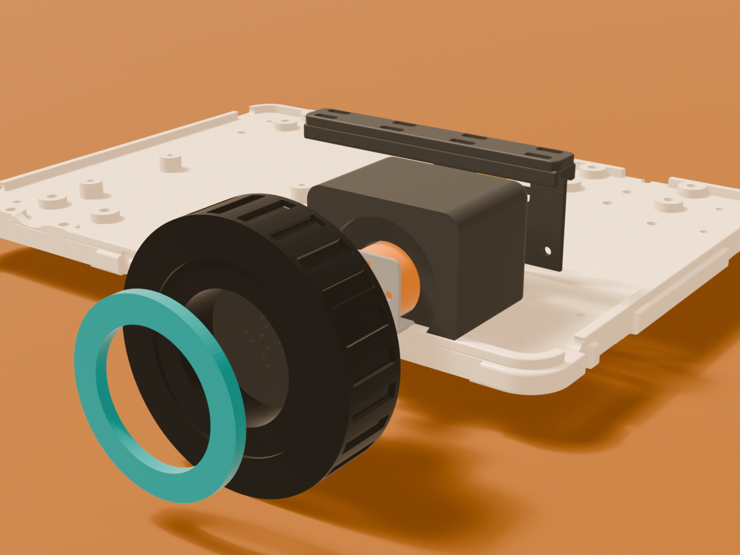
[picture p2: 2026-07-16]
docs/images/codex_robot_body_v1_drivetrain.png

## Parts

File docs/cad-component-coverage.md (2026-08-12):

# v2 Component and Release Coverage

**Current v2 matrix.** Historical v1 coverage is preserved by Git history and
must not be used as a purchase list.

| Area | CAD or source proof | Still required physically |
| --- | --- | --- |
| Body envelope | 238 x 220 x 133 body; inventory validator passes | Printer calibration, large-part warp, delivered-part fit |
| Printed inventory | 40 functional + 4 spare + 1 optional; all solids registered | Print and inspect all production plates |
| Fasteners | 51 modeled M3 x 8 joints and 51 M3 inserts (D049 added the four regulator-bay stations) | Exact lot proofs, insert temperature, torque/service cycles |
| Motors/wheels | Printed saddles/caps, D-bores, tread service ports, axle caps | #4867 revision, torque, retention, wear, current, heat, skid turns |
| Bumpers | Two TPU halves, six switch pockets, rest/stroke/stops modeled | Switch proof, six-zone actuation/rebound, broken-wire stop timing |
| Battery | BLF-1203AB envelope, pad, cradle, clamp, lead corridor | Pack evidence, insulation, retention, current/runtime/BMS/regen/thermal |
| Controller/Pi | MDDS10 and Pi envelopes, airflow and port service | Exact revisions/connectors/thermals; protected mobile Pi input is blocked |
| Power deck | Blue Sea 5045, relay, D24/D36 envelopes and service | Production relay driver/reset/mute fit, terminals, fuses, EE review |
| Rear I/O | EN2 and mute cutouts/envelopes | Pin/polarity/strain, USB mute/backfeed circuit, charger inhibit |
| Head | D85MG/R-ML24 envelopes, journal/bushing, travel and stop sampling | US horn source, fit, grease, load/current/wear/backlash/heat/cable drag |
| Camera/audio/ToF/light | Camera, speaker, mic, side ToF and pixel pockets | Camera retention, amp/pixel/XSHUT mounts, connectors, exact harness |
| Safety logic | Fixed protocol plus Python/C host tests | Qualified production outputs, pin/conditioning review, HIL, binary hash, real stop timing |
| Pi appliance | Closed-world generated image and host attestations | Real Pi, Tunnel, dual UART, collector mutation denial/readback |
| Harness | 28 nominal route records and fail-closed release checker | Every exact terminal, length, pull/continuity result, fuse, thermal/fault result |
| Builder artifacts | Body/proof 3MFs and 45-page guide generate from source | Physical print/fit review and wiring rewrite after blocked parts are selected |

Passing `validate_robot_body_v2.py --gate` proves registered geometry and
kinematics. It does not prove a fuse, crimp, polymer, battery, switch, relay,
motor, servo, or human assembly. Current release holds live in
[`builder-release-v2.md`](builder-release-v2.md) and the executable
[`commissioning/plan-v2.json`](../commissioning/plan-v2.json).

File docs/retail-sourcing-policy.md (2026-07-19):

# Retail Sourcing Policy and v2 Audit

Date: 2026-07-18

Every purchased production item must have a stable manufacturer part number,
primary documentation, and normal quantity-one checkout from a mainstream US
retailer or distributor. Safety/power parts should have two US sources when
practical. RFQ-only, overseas-only, factory-minimum, custom-machined, custom
sheet-metal, and custom-PCB items are rejected unless Brian approves an
exception. Printed parts and assembled harnesses made from retail components
remain allowed.

Availability is volatile. Refresh immediately before ordering; a link is not
stock, and a shopping-cart screenshot is not a datasheet.

## Current v2 audit

| Item | Design identity | Retail state on 2026-07-18 | Release consequence |
| --- | --- | --- | --- |
| Pi 5, Camera 3 Wide, Pico 2 | Raspberry Pi | normal US channels | exact owned/delivered revisions still recorded |
| Motors | Pololu #4867 | product page offered a backorder path | buy one only after stock refresh; mobility purchase blocked |
| Pi regulator | Pololu D24V90F5 | normal specialist-retail trail | not a complete novice-safe Pi input; mobile compute power blocked |
| Servo regulator | Pololu D36V50F6 #4092 | rationed/out of stock during audit | blocked; no substitution without electrical/CAD review |
| Servos | Hitec D85MG | manufacturer and US hobby trail present | exact fit/current tests open |
| Horns | Hitec R-ML24 H24T | easy direct trail found only in Europe | violates US rule; source or redesign required |
| Battery/charger | Bioenno BLF-1203AB/BPC-1502DC | manufacturer quantity-one checkout | complete physical battery gate open |
| E-stop | IDEC XW1E-BV402M-R | stable manufacturer/distributor identity | fit and independent cutoff tests open |
| Motor relay | Panasonic CB1A-R-M-12V | manufacturer identity and US distributor trail | production driver/terminal/dropout/thermal/fault tests open |
| Fuse block | Blue Sea 5045 | normal marine retail trail | every fuse value remains unset |
| Charge connector | Switchcraft EN2P3M20/EN2C3F20G2 | active manufacturer/distributors | pin/polarity/strain tests open |
| Bumper switches | Omron D2HW-C202MR | mainstream distributor family | exact suffix/lead and proof tests open |
| Mobile Pi input | protected Pi 5 battery input | no accepted part/interface | **hard sourcing/design blocker** |
| Physical reset | Pico-local momentary control | no accepted part/location | **hard design blocker** |
| Mic mute/backfeed gate | protected USB data/power interface | no accepted exact circuit/parts | **hard electrical blocker** |

The current purchase authority is
[`builder-release-v2.md`](builder-release-v2.md). Older audits that discuss
metal motor brackets, wheel hubs, bearings, shoulder bolts, standoffs, spacers,
straps, or split-body hardware are v1 history after D025-D026.

## Substitution rule

A substitute is a design change, not a checkout convenience. Re-run sourcing,
datasheet, envelope/service, electrical, thermal, firmware, CAD, print, guide,
and physical gates affected by the change. Never silently substitute a motor,
servo horn, regulator, battery, relay, switch contact form, or connector.

## Purchase batches

1. Buy only filament, the two body-fastener packs, bench supplies, and one
   sample of each fit-critical component needed for proofs/dry fit.
2. Close delivered-fit and bench electrical gates before paired motors,
   servos, horns, regulators, or harness inventory.
3. Buy final wire, terminals, and fuses only from the measured, reviewed
   harness plan. There is intentionally no “close enough” robot-wiring aisle.

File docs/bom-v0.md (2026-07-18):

# BOM v0: Codex House Companion MVP — HISTORICAL V1 ONLY

> **Do not purchase or assemble v2 from this file.** This page is a compact
> record of retired v1 assumptions. The only current v2 selection list and
> purchase blockers are in [`builder-release-v2.md`](builder-release-v2.md).

Date of the original estimate: 2026-07-06

The original BOM mixed a useful early product sketch with metal drivetrain,
idler, fastener, and speculative electrical purchases that D025-D028 later
removed. Leaving live shopping verbs beside those rows was unsafe for a
builder who landed here from search, so the obsolete checkout table is no
longer reproduced in the active documentation tree. Git history preserves it
for forensic comparison.

## Retired v1 assumptions

| Historical assumption | Why it is not a v2 instruction |
| --- | --- |
| Pololu #1569 metal motor brackets | v2 uses printed saddles and caps. |
| Pololu #1997 aluminum wheel hubs | v2 wheels clamp directly to the motor D-shafts. |
| 608 bearings, WDS shoulder bolts, M6 hardware, and goBILDA spacers | v2 front pods use printed axle/bushing load paths. |
| Purchased standoffs, spacers, straps, and multiple screw sizes | v2 body hardware is one M3 insert SKU plus one M3 × 8 screw SKU; only documented component-integral hardware is exempt. |
| Inline fuse/connector shopping from guessed loads | v2 has separate battery-near motor and accessory feeder fuses, but every fuse value, exact holder, terminal, conductor, and connector remains unreleased. |
| A complete mobile Pi power path | the protected locking Pi input, backfeed protection, downstream fusing, boot/load margin, and thermal proof remain blocked. |
| A complete servo/head power path | the D36V50F6 availability and two-servo transient/thermal qualification remain blocked. |
| A generic service-switch cluster or software-reset assumption | v2 still needs a selected, protected Pico-local physical reset. |

## Current route

Use these artifacts, in order:

1. [`builder-release-v2.md`](builder-release-v2.md) for current selections,
   sourcing state, and explicit holds.
2. [`../output/pdf/codex_robot_body_v2_assembly_guide.pdf`](../output/pdf/codex_robot_body_v2_assembly_guide.pdf)
   for coupon-first dry assembly.
3. [`retail-sourcing-policy.md`](retail-sourcing-policy.md) for the live retail
   rule and substitution policy.
4. [`../harness/README.md`](../harness/README.md) and
   [`first-article-evidence.md`](first-article-evidence.md) for the intentionally
   red electrical and physical release gates.

The v2 body can be printed and dry-assembled only after the coupons pass. It
is not a complete retail kit and this historical filename grants no powered
motion authority. Tiny robot archaeology belongs in Git, not in a shopping
cart.

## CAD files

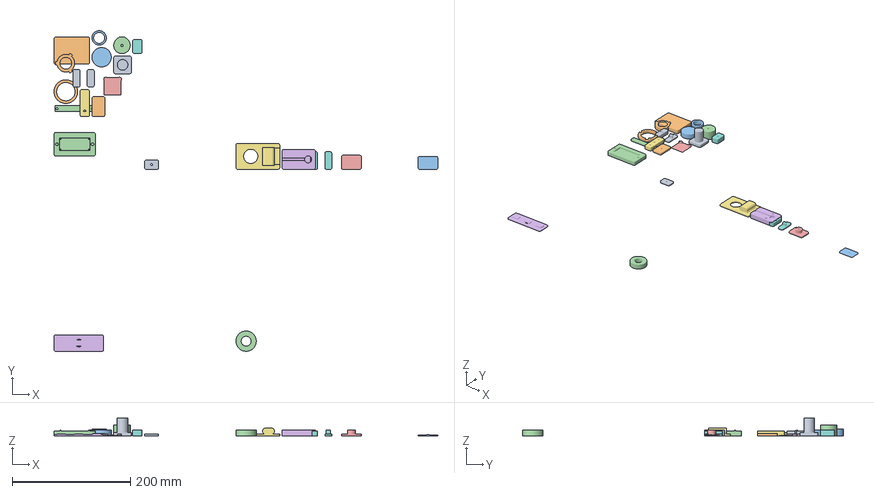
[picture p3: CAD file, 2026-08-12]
cad/bambu/codex_robot_body_v2_proofs_p1s.3mf
648.4 x 541.5 x 30.0 mm
proof_axle_stub.stl
proof_bayonet_pair.stl
proof_bushing_ring.stl
proof_dbore_torque.stl
proof_horn_capture_cover.stl
proof_horn_capture_cradle.stl
proof_insert_m3.stl
proof_joint_boss.stl
proof_joint_flange.stl
proof_lid_boundary_petg.stl
proof_lid_boundary_pla.stl
proof_pcb_clamp.stl
proof_pla_insert_shell.stl
proof_pla_optical.stl
proof_pla_shell_wall.stl
proof_pla_snap_pair.stl
proof_snap_pair.stl
proof_switch_pocket.stl
proof_tire_fit_core.stl
proof_tire_fit_ring.stl

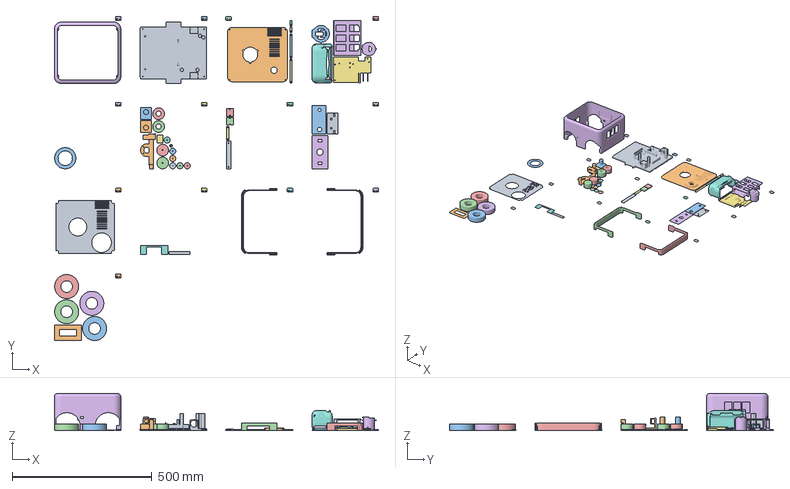
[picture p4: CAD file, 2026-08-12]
cad/bambu/codex_robot_body_v2_p1s.3mf
1160.6 x 1159.6 x 133.0 mm
battery_clamp_v2.stl
battery_pad_frame_v2.stl
bayonet_collar_v2.stl
bumper_front_v2.stl
bumper_rear_v2.stl
controller_tower_v2.stl
deck_v2.stl
eye_diffuser_bar_v2.stl
fascia_v2.stl
front_pod_left_v2.stl
front_pod_right_v2.stl
front_wheel_v2_i1.stl
front_wheel_v2_i2.stl
head_faceplate_v2.stl
head_pan_plate_v2.stl
head_shell_v2.stl
lid_skin_v2.stl
lid_v2.stl
mic_cradle_v2.stl
motor_cap_v2_i1.stl
motor_cap_v2_i2.stl
neck_v2.stl
pico_clamp_v2.stl
printed_washer_v2_i1.stl
printed_washer_v2_i2.stl
printed_washer_v2_i3.stl
printed_washer_v2_i4.stl
printed_washer_v2_i5.stl
printed_washer_v2_i6.stl
qc_tab_p1.stl
qc_tab_p10.stl
qc_tab_p11.stl
qc_tab_p12.stl
qc_tab_p13.stl
qc_tab_p2.stl
qc_tab_p3.stl
qc_tab_p4.stl
qc_tab_p5.stl
qc_tab_p6.stl
qc_tab_p7.stl
qc_tab_p8.stl
qc_tab_p9.stl
rear_panel_v2.stl
rear_wheel_v2_i1.stl
rear_wheel_v2_i2.stl
shell_v2.stl
speaker_clamp_v2_i1.stl
speaker_clamp_v2_i2.stl
status_diffuser_bar_v2.stl
tilt_bushing_v2.stl
tire_v2_i1.stl
tire_v2_i2.stl
tire_v2_i3.stl
tire_v2_i4.stl
tof_clamp_v2_i1.stl
tof_clamp_v2_i2.stl
tray_v2.stl
yoke_v2.stl

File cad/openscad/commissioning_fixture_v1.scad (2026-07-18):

// RB-FIXTURE-V1: one support-free PETG plate for unpowered commissioning.
// Print exactly as modeled: component face at Z=0, hollow feet upward. Flip for use.

include <generated/commissioning_fixture_v1_data.scad>

$fn = 48;
epsilon = 0.1;
foot_outer = 24;
foot_wall = 2.4;
rib_width = 4;
rib_height = 8;

module rounded_slot(length, width, height) {
    hull() {
        translate([-(length - width) / 2, 0, 0]) cylinder(d=width, h=height);
        translate([(length - width) / 2, 0, 0]) cylinder(d=width, h=height);
    }
}

module hollow_foot(x, y) {
    difference() {
        translate([x - foot_outer / 2, y - foot_outer / 2, plate_thickness])
            cube([foot_outer, foot_outer, foot_height]);
        translate([
            x - foot_outer / 2 + foot_wall,
            y - foot_outer / 2 + foot_wall,
            plate_thickness - epsilon
        ])
            cube([
                foot_outer - 2 * foot_wall,
                foot_outer - 2 * foot_wall,
                foot_height + 2 * epsilon
            ]);
    }
}

module underside_ribs() {
    inset = 15;
    translate([-plate_width / 2 + inset, -plate_depth / 2 + inset, plate_thickness])
        cube([plate_width - 2 * inset, rib_width, rib_height]);
    translate([-plate_width / 2 + inset, plate_depth / 2 - inset - rib_width, plate_thickness])
        cube([plate_width - 2 * inset, rib_width, rib_height]);
    translate([-plate_width / 2 + inset, -plate_depth / 2 + inset, plate_thickness])
        cube([rib_width, plate_depth - 2 * inset, rib_height]);
    translate([plate_width / 2 - inset - rib_width, -plate_depth / 2 + inset, plate_thickness])
        cube([rib_width, plate_depth - 2 * inset, rib_height]);
}

module fixture_blank() {
    union() {
        translate([-plate_width / 2, -plate_depth / 2, 0])
            cube([plate_width, plate_depth, plate_thickness]);
        for (x = [-plate_width / 2 + 15, plate_width / 2 - 15])
            for (y = [-plate_depth / 2 + 15, plate_depth / 2 - 15])
                hollow_foot(x, y);
        underside_ribs();
    }
}

module through_holes() {
    hole_height = plate_thickness + 2 * epsilon;
    translate([estop_center[0], estop_center[1], -epsilon])
        cylinder(d=estop_hole_diameter, h=hole_height);
    translate([lamp_center[0], lamp_center[1], -epsilon])
        cylinder(d=lamp_hole_diameter, h=hole_height);

    for (center = bumper_centers)
        for (offset = [-bumper_hole_spacing / 2, bumper_hole_spacing / 2])
            translate([center[0] + offset, center[1], -epsilon])
                cylinder(d=3.4, h=hole_height);

    for (center = [driver_tie_center, relay_tie_center])
        for (offset = [-15, 15])
            translate([center[0] + offset, center[1], -epsilon])
                rotate([0, 0, 90]) rounded_slot(12, 3.2, hole_height);

    // Two cable-management stations beside the breadboard.
    for (y = [20, 76])
        translate([-106, y, -epsilon]) rounded_slot(14, 3.2, hole_height);
}

difference() {
    fixture_blank();
    through_holes();
}

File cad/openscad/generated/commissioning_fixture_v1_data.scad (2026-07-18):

// Generated by commissioning/fixture.py; do not hand-edit.
fixture_id = "RB-FIXTURE-V1";
plate_width = 232;
plate_depth = 210;
plate_thickness = 4;
foot_height = 75;
breadboard_center = [-28, 48];
breadboard_size = [165, 55];
estop_center = [82, 55];
estop_hole_diameter = 22.3;
lamp_center = [82, 13];
lamp_hole_diameter = 6.2;
bumper_centers = [[-80, -69], [-48, -69], [-16, -69], [16, -69], [48, -69], [80, -69]];
bumper_hole_spacing = 13;
driver_tie_center = [18, -16];
relay_tie_center = [65, -18];

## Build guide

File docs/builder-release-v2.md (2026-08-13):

# Rover Bean Builder Release — v2.0.0-prototype.5

Permanent source: [https://github.com/brianpattison/robot/releases/tag/v2.0.0-prototype.5](https://github.com/brianpattison/robot/releases/tag/v2.0.0-prototype.5)

## Verdict

This is a **prototype geometry, dry-assembly, and bench-software release**. It is
not authorization for powered motion and it is not a complete retail kit. The
tracked body/head geometry and hardware-free tests pass; every delivered-part,
electrical, loaded-motion, and commissioning result remains specific to the
physical first article.

## One-version artifact map

| Artifact | Path | Release meaning |
| --- | --- | --- |
| Builder's Book | `output/pdf/codex_robot_body_v2_assembly_guide.pdf` | Picture-first dry assembly plus explicit release holds. |
| Body print project | `cad/bambu/codex_robot_body_v2_p1s.3mf` | 45 prototype pieces on 13 material-separated plates. |
| Proof print project | `cad/bambu/codex_robot_body_v2_proofs_p1s.3mf` | 18 logical tests / 20 objects / 5 material-separated plates. |
| UART contract | `docs/body-protocol-v1.md` | Fixed v1 bench protocol; no flash/config-write path. |
| Pi body daemon | `software/robotd/` | Executable local Unix-socket/UART baseline with blackbox logging. |
| Pi 5 appliance | `software/appliance/` + `software/install.sh` | Closed-world Bookworm provisioning baseline; real Pi, Tunnel, dual-UART, and append-only collector attestations remain open. |
| Pi provisioning guide | `docs/pi-appliance-provisioning.md` | The full appliance recipe the book's "Move the brain into the robot" page condenses. |
| Supervision dashboard | `software/dashboard/` | Localhost-only `robotd` client: status, decoded safety flags, bumper zones, hold-to-drive, blackbox tail. Not a safety device. |
| Pico safety firmware | `firmware/pico2-safety/` | Tested portable safety core plus a deliberately fail-stopped Pico integration. Production motor outputs are absent. |
| Harness traveler | `harness/harness-v2.json` | 28-route engineering schedule; exact terminals, measured lengths, fuses, and physical evidence remain red. |
| Commissioning evidence | `commissioning/plan-v2.json` + `docs/first-article-evidence.md` | Executable 27-step gate plus content-addressed, externally signed per-robot bundles; no physical pass is bundled. |
| Unpowered commissioning fixture | `commissioning/fixture-v1.json` + `docs/commissioning-fixture-v1.md` | Closed-world circuit, one support-free PETG plate, and USB-logic/0.20 A negative-control guide; no physical pass is bundled. |

## Filament

| Product slot | Buy | Role |
| --- | --- | --- |
| White PETG | one 1 kg spool; confirm the slicer estimate | white general and enclosure-fallback structure (5 plates). |
| Black PETG | a small spool or known-good leftovers | black motion and wear structure (1 plate). |
| Red PETG | a small spool or known-good leftovers | red battery, safety-board, and motor retainers (1 plate). |
| Charcoal PLA | a small spool or known-good leftovers | direct visible cosmetic parts; physical fit/temperature gates open (1 plate). |
| Teal PLA | a small spool or known-good leftovers | direct visible cosmetic parts; physical fit/temperature gates open (1 plate). |
| Translucent lime PLA | a small spool or known-good leftovers | light diffusers; optical/thermal gates open (1 plate). |
| Charcoal TPU 95A | one 500 g spool | tires, bumper halves, battery pads (3 plates). |
| Candidate body-color PLA (optional) | one spool per color you audition | Proof try-out only: the shell/head color you hope to qualify. Those parts print white PETG until a candidate passes its recorded checks. |

## Fasteners

| Exact size | Buy | Role |
| --- | --- | --- |
| M3 × 8 mm socket head screws | one 100-pack | The ONLY screw in the robot (51 used + spares). |
| M3 × 5.7 mm brass heat-set inserts (4.6 mm OD) | one 100-pack | The only insert (51 used + spares). |

## Electronics and purchased hardware

This table is the prototype selection list, not blanket purchase authorization.
Any row whose fit, termination, load, or test evidence is open stays open.

| Part | Qty | Role / hold |
| --- | --- | --- |
| Raspberry Pi 5 (8 GB) | 1 | The robot’s computer. |
| 32 GB+ A2 microSD card | 1 | The computer’s memory card — the robot’s programs live here. |
| Raspberry Pi Camera Module 3 Wide + Pi 5 camera cable (22-pin, 300 mm) | 1 | The robot’s eye. The Pi 5 uses the small 22-pin camera connector — the 15-pin cable in the camera box fits older Pis, not this one. |
| Raspberry Pi Pico 2 (no headers, no WiFi) | 1 | The safety helper: reflexes and watchdog. |
| Cytron MDDS10 motor driver | 1 | The purple board that powers the wheels. |
| Pololu #4867 gearmotor (99:1, 25D, 12 V, encoder) | 2 | The wheel motors. |
| Hitec D85MG servo | 2 | The neck motors (look left/right, up/down). The single arm, spline screw, grommets, and eyelets in each servo's own bag are the drive parts — the old metal-horn and hardware-pack rows are retired (D048), so there is nothing extra to buy. Confirm the delivered arm against the horn-capture proof before the head steps. |
| Bioenno BLF-1203AB 12 V 3 Ah LiFePO4 battery | 1 | The robot’s power pack. |
| Bioenno BPC-1502DC charger | 1 | The matching charger. Only ever use this one. |
| Switchcraft EN2P3M20 inlet + EN2C3F20G2 plug | 1 pair | The keyed charging plug on the back. |
| Pololu D24V90F5 regulator (5 V) | 1 | Safe to buy — the settled pick, and since D053 it feeds the head servos too (the separate 6 V rail is retired; its deck bay stays as a reserved spare). What stays BLOCKED is wiring it: the novice-safe locking Pi input, backfeed protection, downstream fusing, boot/load margin, thermal proof, and the shared-rail servo-transient bench test are open; never feed the GPIO header from this preview. |
| Panasonic CB1A-R-M-12V relay | 1 | The motor power switch the red button controls. |
| Production relay driver | not released | BLOCKED, but the candidate is selected (D054): the fixture's Adafruit 5648 MOSFET driver, promoted from negative-control duty. Exit: positive-control conditioning, fit, and EE review — one bench session with a part already in the fixture box. |
| Pico-local physical reset | not released | BLOCKED, but the candidate is selected (D055): a seventh Omron D2HW — the same switch the bumpers already trust — recessed behind a printed guard in the rear service corridor. Exit: conditioning circuit + CAD pocket. |
| Blue Sea Systems 5045 fuse block | 1 | Splits power safely into fused branches. D058 proposes replacing it with two sealed inline ATO holders now that the 6 V branch is retired — hold this purchase if you want to wait for that decision. |
| ATO/ATC fuse assortment box | 1 | Buy the cheap assortment; INSTALL NOTHING. Every value stays a release gate until measured load, conductor, inrush, time-current, selective-clearing, and thermal evidence is reviewed — owning fuses is harmless, installing unproven values is not. |
| IDEC XW1E-BV402M-R emergency stop | 1 | THE BIG RED BUTTON. |
| E-Switch PVB3F230SS311 mute switch | 1 | The microphone privacy switch (glows red when muted). |
| Omron D2HW-C202MR bumper switches | 6 | Feelers inside the bumpers. |
| VL53L1X time-of-flight boards (Adafruit 3967) | 2 (+2 optional) | Distance eyes. Two in front are the baseline; the side pair is optional garnish (D057) — the bumpers are the safety floor and the camera is the perception plan. The side windows and clamps stay in the prints either way. |
| Adafruit 5975 NeoPixel breakouts + JST-SH cables | 4 | The glowing eyes and status lights. |
| USB microphone (any small one to start; ReSpeaker array as the upgrade) | 1 | The robot's ears. Any plain USB mic clears bring-up (D060); the ReSpeaker array slot remains for when the voice software earns it — its exact revision plus the true VBUS-cut/no-backfeed mute interface remain BLOCKED either way. |
| Enclosed 3 W 4 ohm speakers + 2× Adafruit MAX98357A amps | 1 set | The robot’s voice. |
| Harness bench stock (WAGO 221-412/415 lever nuts, label tape, wire in the traveler's published gauges) | 1 set | Safe to buy under the D047 termination policy — lever nuts are already trusted fixture hardware. Owning stock is not wiring: the battery stays out and nothing gets crimped until the release below. |
| Production terminals + measured cut list | not released | The exact terminal schedule, measured lengths, and the one named crimper are still open; do not improvise a powered harness from this preview. |

## Bench equipment

The commissioning plan's acceptance thresholds assume these instruments; they
are commissioning tools, not robot parts, and none of them ride in the body.

| Instrument | Qty | What it proves |
| --- | --- | --- |
| Current-limited DC bench supply (0–15 V, ≥3 A, settable current limit) | 1 | Regulator bring-up (C006), the fixture's 0.20 A negative-control stage, the low-battery sweep (C017), and the 6 V servo bench (C022). A settable limit is the requirement; programmable sweep is a convenience. |
| Multimeter with continuity beeper, mV resolution, and 0.01 A DC current | 1 | Every continuity check in the harness traveler, the ≤100 mV mute/backfeed readings (C018), and the per-motor / pack current ceilings (C024). |
| Contactless IR thermometer (or thermocouple meter) | 1 | Terminal, conductor, servo, motor, driver, and pack temperature evidence (C019, C022, C024, C025). |
| Raspberry Pi Debug Probe (SC0889) | 1 | Already in the fixture BOM: the Pi debug-console attestation cable, the Pico service corridor, and the one-time independent cross-check of the firmware's self-reported stop-latency telemetry. |

## Bench commands

```bash
python3 commissioning/run_host_tests.py
python3 software/appliance/appliance.py --check
python3 commissioning/fixture.py --check
python3 harness/generate_harness_docs.py
python3 harness/generate_harness_docs.py --release
python3 commissioning/commission.py list
python3 commissioning/commission.py show C001
```

The first three commands must pass without robot hardware. The two release
gates are intentionally red until the exact first article supplies every
required measurement and test record. Final evidence verification also requires
the sealed bundle, expected robot serial, and an independently administered
OpenSSH `allowed_signers` / revocation policy.

## Powered-motion release remains blocked on

- A protected mobile Pi 5 input, the D053 shared-rail servo transient proof
  (the separate 6 V regulator is retired; its bay is a reserved spare), the
  production relay driver (candidate selected: the fixture's Adafruit 5648,
  D054), and the Pico-local physical reset (candidate selected: a seventh
  Omron D2HW behind a printed guard, D055). The R-ML24 sourcing blocker is
  retired by D048's printed arm-capture cradle, pending the delivered-arm
  proof.
- Exact delivered-part fit and the completed 18-proof record.
- Exact connector housings/contacts, measured harness lengths, continuity and
  pull tests, released fuse values, selective-fault tests, and thermal soak.
- Reviewed conditioned-input, relay-driver, battery-sense, motor-output, and
  encoder integration; the shipped Pico target can never enable the motors.
- E-stop, all six NC bumper zones, broken-wire behavior, watchdog, independent
  setpoint lease, charger inhibit, low-battery cutoff, and hardware mic-mute
  fixture results.
- Head wear/current/cable-drag, wheel retention, target-floor current,
  45-minute runtime/reserve, real Pi/Tunnel/dual-UART proof, append-only off-host
  audit readback and denied-mutation proof, and closure inspection.
- Real first-article wiring and hidden-layer photographs.

If a field is blank, the answer is not “probably.” The answer is “open.” Tiny
robot, enormous respect for empty checkboxes.

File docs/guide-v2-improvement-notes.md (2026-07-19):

# Builder's Book v2 — Review Findings and Improvement Plan

*Dated record, written before D038 renamed the v2 "coupons" to "proofs";
historical wording retained.*

A full page-by-page review of `output/pdf/codex_robot_body_v2_assembly_guide.pdf`
(originally 37 pages), the step renders in `docs/images/guide_v2/`, the hero renders, and the
v2 CAD model behind them. Findings are grouped by root cause; each has the fix
applied (or proposed). Items marked **[fixed]** were implemented in this pass.

## A. Real model/content bugs (would mislead a builder)

- **A1. Left/right directions mirrored for the deck-area electronics.** The robot
  faces −X, so the robot's RIGHT is +Y. Several instructions used the mirrored
  convention. Per the registered inventory (`robot_body_v2_inventory.py`):
  - Fuse block sits on the deck's **left** half (Y −67..−23), wire service off the
    **left** edge — the book said "right half" / "wire exit RIGHT edge" (steps 12,
    p32 table). **[fixed]**
  - MDDS10 terminal service faces +Y = robot **right** — the book said terminals
    face LEFT (step 7, p32). **[fixed]**
  - Regulators hang under the deck's **rear** portion (X 60..112), and the 6 V
    wire service faces −X = **front** — the book said "right end" and "6 V wire
    exit LEFT" (step 12, p32). **[fixed]**
  - Pico USB corridor faces +X = robot **back** — the book said "USB plug facing
    RIGHT" (step 10, p32). **[fixed]**
  - The controller tower spans the tray's front **center** (Y ±59), not
    "front-left" (step 7). **[fixed]**
  - Correct as written (checked, unchanged): relay on the left, battery wires to
    the back, Pico to the right of the tower, deck notch at back-right.
- **A2. Eye diffuser bar cannot reach the eyes.** The head faceplate's two eye
  slots sit at Y ±40 (80 mm apart, 9 × 14 mm each), but `build_eye_diffuser_bar`
  was a 30 mm bar with pads at ±5 — physically unable to serve both eyes, while
  the part registry says "both eye diffusers as one bar". Rebuilt as a 98 mm bar
  with one 8.4 × 13.4 mm pad entering each slot. **[fixed]**
- **A3. Status diffuser bar pads had zero clearance.** 10 mm pads into 10 mm
  fascia slots. Pads resized to 9.4 × 4.4 mm for a real snap fit. **[fixed]**
- **A5. Rear clamp screw buried under the tire.** The rear wheel's radial
  clamp-screw bore exits at the rim's surface (wheel Y-center), and the TPU
  tire is exactly the wheel's width — once the tire is stretched on, the screw
  hole is covered and step 6 ("push the wheel on, then tighten the clamp
  screw") is impossible. The guide's "little bump on the rim" never existed in
  the model. Fixed by molding one 7.2 mm radial access port into the tire
  tread: melt the rim insert with the tire off (step 4 already orders it that
  way), align the port over the screw hole when stretching the tire on, and
  drive the clamp screw through the port in step 6. All four tires share the
  design; the front pair's port is simply unused. Steps 4/6 text updated.
  **[fixed]**
- **A6. Neither wheel retention actually worked (Brian's catch, 2026-07-17).**
  Looking at the step-4 render, Brian asked how the tire insert could possibly
  work — and checking the numbers showed the whole retention stack was fiction:
  - *Rear:* the clamp-screw insert bore opened at the rim surface, so an
    M3 × 8 threaded into it ended ~12 mm short of the motor shaft. The screw
    would spin in free air. The bore is now a stepped well — a 7.4 mm
    head/tool channel from the rim, the 4.6 mm insert seat deep in the wheel,
    and tip clearance ending 0.3 mm past the shaft flat, so the single-SKU
    M3 × 8's tip presses the flat snug. The insert drops down the well and is
    pressed home with the iron tip (still with the tire off, as step 4 orders).
  - *Front:* the printed washer was 8 mm OD — smaller than the front wheel's
    18.5 mm bore, so it retained nothing; the wheel could slide straight off
    past it. It is now a 22 mm OD × 3.2 mm cap washer that overlaps the bore
    lip, and its 3.2 mm face makes the front-axle joint honest against the
    D026 clamp-stack rule (the old 1.6 mm washer violated it).
  Steps 4/6 rewritten to match; step 2 now explains that the gold pegs in the
  pictures are pointers, not parts. **[fixed]**
- **A4. Piece names differ between the plate table (p8) and the piece chart
  (p10).** "deck / controller tower / pico clamp / tof clamp / head pan plate"
  vs "power deck / brain tower / safety-board clamp / sensor clamp / head bottom
  plate". A kid can't match them. Plate table now uses the same friendly names
  as everywhere else. **[fixed]**

## B. Step-render correctness bugs

- **B1. Stray gold dot on the tray in steps 5–12.** The brass-insert proxy
  (`px_insert`, spec location 0,0,60) was appended to the `placed` list after
  step 2, so it rendered mid-tray in every later step. Fastener proxies are no
  longer placed. **[fixed]**
- **B2. Floating clamp bars in the chassis hero render** (Build-It opener p11,
  wiring p32, back cover p37). The chassis view hides the shell but kept the
  speaker/ToF/battery/pico clamp bars, which clamp purchased parts that are not
  in the base scene — so bars float in mid-air. The chassis view now hides
  clamp-type parts too. **[fixed]**
- **B3. Six feeler switches, one proxy.** Step 14's GATHER says ×6 but the scene
  had a single switch proxy (and it was invisible in the shot). Six switch
  proxies now sit in the six real tray pockets, and the step camera is a low
  angle that shows them entering the pockets. **[fixed]**
- **B4. Front distance boards never rendered.** Step 15 lists ×2 front ToF
  boards, but no proxies existed at the front stations; the check line "two tiny
  lenses look out of the face" had no visual support. Front ToF proxies added
  behind the fascia apertures. **[fixed]**
- **B5. Lime light bars absent everywhere.** The diffuser bars were exported
  unplaced and hidden in every render, so the fascia/status slots showed the
  interior (a green Pi surface read as a mystery green square on p27/p28), and
  the "meet the robot" caption pointed at glowing bars that don't glow. The
  bars are now placed (fascia + head) with an emissive lime material in the
  assembled/rear heroes and in steps 15+. **[fixed]**

## C. Step-render clarity (the "renderings don't look right" list)

- **C1. No visual link between a floating part and its destination.** The
  LEGO-style "pop" offsets parts 32 mm, but nothing points at the landing spot —
  ambiguous for the motors (which cradle?), pods, Pico, relay, deck, shell, lid,
  head. The final renderer exports normalized part/destination coordinates
  from the evaluated camera, and the guide draws crisp numbered magenta 2D
  arrows with matching numbered landing dots. This removes shadow, occlusion,
  and perspective-scale ambiguity while keeping every pointer registered to
  the actual CAD scene. Dedicated detail panels replace dense arrows where a
  hidden interface needs a section. **[fixed]**
- **C2. Pops along the wrong axis.** Wheels/washers popped straight up (+Z) even
  though they slide sideways onto shafts; bumper halves popped up instead of
  wrapping front/back; the deck pop (+32) left the deck impaled on a tower;
  speakers popped to exactly rim height, reading as "parked on the rim edge".
  Pops are now per-part: wheels/washers pop outboard ±Y, bumpers pop ±X,
  deck/shell/lid pop higher (+55..70), speakers pop above the rim with the
  interior camera. **[fixed]**
- **C3. Wheel-prep step (4) rendered parts scattered at assembly stations in
  mid-air** at wildly different distances (one giant foreground tire, one wheel
  cut off, phantom shadows). The bench step now lays the four wheel+tire
  assemblies flat on the floor in a neat 2×2 grid at matched scale, back-wheel
  hub inserts marked in gold. **[fixed]**
- **C4. Insert locations only marked for the tray.** Step 2's "gold marks every
  spot" convention was dropped for the shell's 14 inserts (step 13), the lid's 2
  (step 17), the wheels' 2 (step 4), the pods' 2 (step 5), and the head's 1
  (step 19). All insert batches now render gold markers; steps 13 and 17 get an
  **inset panel** (shell alone / lid flipped) showing every insert spot.
  **[fixed]**
- **C5. Cameras bury the action.** One "body" camera serves 12 steps, so small
  parts (Pico, relay, regulators) are far away and the same picture repeats;
  meanwhile the CSS zooms every image to 118%, cropping wheels (pp. 17–23) and
  the E-stop (pp. 28–29). Camera set expanded (interior view for speakers, low
  bumper view, tighter deck/tower framing), and the CSS zoom dropped so the
  full frame shows. **[fixed]**
- **C6. Proxy shapes too abstract to orient.** The Pi was a featureless green
  slab ("USB ports face BACK" — invisible); the MDDS10 was pink though the text
  says "purple board with green terminal blocks"; motors were plain cylinders
  (no shaft to point OUT); the camera was a green slab (reads as a PCB, not a
  lens). Proxies upgraded: Pi gets a dark port block, MDDS10 is purple with a
  green terminal strip on its right edge, motors get silver shafts, the camera
  gets a dark lens barrel, the relay gets its bracket flange. **[fixed]**
- **C7. Hero crops decapitate the robot.** The rear hero camera cut the head at
  the frame top (p2 "from the back", also echoed on p36); the cover crop is
  intentional but the meet-page needs the whole robot. Rear/assembled cameras
  pulled back and re-aimed; meet-page callout percentages re-tuned. **[fixed]**
- **C8. Dark plates unreadable on p7.** Charcoal/TPU parts on Bambu's dark plate
  thumbnails are nearly invisible (plates 7, 9–11). The contact-sheet generator
  now lifts the shadows on dark thumbnails so silhouettes read. **[fixed]**

## D. Guide text / layout improvements

- **D1.** Step 10 checked "USB port is reachable" while the wiring chapter is the
  only time it's needed — reworded to match the correct orientation (A1) and
  when it matters. **[fixed]**
- **D2.** Step 12 re-ordered to match the fixed geometry: regulators under the
  rear half, fuse box on the left half, wire tail over the left edge. **[fixed]**
- **D3.** Step 18's collar/servo work is invisible under the lid; the text now
  tells the builder the picture shows the hole they reach through, and the
  neck-cam frames the lid hole without cropping the E-stop. **[fixed]**
- **D4.** Step 1's orientation anchor ("motor cradles at the back") now matches a
  render with the FRONT arrow overlaid at the tray's front edge (the chip alone
  was easy to miss). Implemented as part of C1's arrow system. **[fixed]**
- **D5.** Meet-page callouts re-anchored after the hero reframe (C7). **[fixed]**

## E. Noted, deliberately not changed (for discussion)

- **E1.** The head render on the cover is cropped tight on purpose (styling); the
  uncropped robot appears on p2.
- **E2.** MAX98357A mounts, channel straps, terminal service, and strain relief
  remain an explicit prototype hold; the current book no longer invents a
  zip-tie location.
- **E3.** Step 14's bumper halves genuinely float loose by design (they squish to
  press the switches); the check line covers it.
- **E4.** Superseded by D034/D035: the live manifests now report 40 installed
  functional pieces + 4 spare washers + 1 optional skin = 45 pieces, 47 M3
  screws/inserts, 13 plates, seven material/color groups, and 18 coupons.
- **E5.** A dedicated wiring-photo appendix (real harness photos) would help
  once a physical build exists; out of scope for renders.

## F. External assembly-review follow-up (2026-07-17)

- **F1. Prototype truthfulness. [fixed]** Cover, README, 3MF notes, wiring,
  software, fuse, and commissioning pages now distinguish dry-build geometry
  from powered-motion release. Page topology is Pi/`robotd` -> Pico framed UART
  -> MDDS10; Pico USB/SWD are service-only.
- **F2. Hybrid materials. [fixed]** D034 separates family, role, and theme;
  direct PLA, qualified PLA candidates with automatic PETG fallback, the
  optional lid skin, 18 evidence coupons, per-family plates, and exact counts
  all derive from the canonical inventory.
- **F3. Head mechanism. [CAD fixed; physical gates open]** D035 replaces every
  placeholder with a three-lug collar, printed pan journal/thrust face,
  integrated servo cradle, two-M3 pan plate, horn drive, 20 mm ribbon corridor,
  four-M3 yoke, drawing-backed tilt-servo frame, active shell boss, passive
  shoulder bushing, and physical pan/tilt stops. The validator samples actual
  solids through both commanded ranges and proves stop engagement beyond them.
- **F4. Head instructions. [fixed]** Steps 18–19 now list both R-ML24 horns and
  the verified component hardware pack, give an ordered servo/horn/bushing
  sequence, and use separate pan, tilt, passive-pivot, and camera panels.
- **F5. Render legibility. [fixed]** Every assembled hero retains the dark
  camera lens; white PETG gets a temporary cool-grey instructional tint and
  stronger rim; page 32/back use a populated cutaway. Close panels now cover
  Pico orientation, regulator/fuse sides, all six bumper switches, rear panel,
  audio, the full E-stop stack, pan, tilt, and camera. Dimensioned vector
  sections now expose the rear-wheel well and shaft clamp, front cap washer,
  bumper stroke/stop, fascia back, audio orientation, E-stop load path, and
  status-light order. Numbered arrows are exported from the real camera scene.
- **F5a. Coupon project and records. [fixed as an artifact; evidence open.]**
  The 18 logical qualification tests now ship as a tracked five-plate Bambu
  project with 19 material-correct objects; the PETG tire core and TPU ring are
  separate. The book shows the project before the test tables and requires
  machine/filament/settings/result/tester/date records.
- **F6. Executable artifacts fixed; physical evidence still open by design.**
  The repo now ships the framed v1 UART contract, local `robotd`/installer,
  host-tested portable Pico safety core, deliberately fail-stopped Pico target,
  28-route nominal harness traveler with a red release gate, and executable
  27-step commissioning package. Exact harness terminals and measured lengths,
  MAX98357A mounting, NeoPixel installation, production motor/encoder outputs,
  released fuse values, physical photos, and signed commissioning results still
  require delivered hardware and bench evidence; the book remains a prototype
  preview until they exist.
- **F7. Builder usability follow-up. [fixed]** The 42-page book now adds a
  purchased-electronics visual matching page, 13 cut-apart plate/bin labels,
  an 18-row printable coupon qualification record, and QR links to the
  immutable `v2.0.0-prototype.2` Builder Release Index. That index generates
  the exact prototype BOM, artifact paths, bench commands, and open-gate list
  from the same authored shopping data as the book. The commissioning gate now
  checks fixed acceptance predicates as well as field presence, so a record
  marked pass still fails if (for example) protocol clear succeeded, a service
  cable remained connected, a clamp exceeded its limit, or mirror gap/recovery
  evidence was not observed.

## G. From-scratch buildability review (2026-07-19)

A cold-reader pass: can a stranger with only the PDF and a credit card reach a
finished dry build? Fixes shipped with release `v2.0.0-prototype.3`.

- **G1. Build source unreachable. [fixed]** The QR pointed at a tree URL on a
  then-private repo with no published releases. The repo is now public,
  `RELEASE_URL` points at the GitHub *release* page (downloadable 3MFs + PDF
  assets), and Chapter 2 tip 1 plus both QR captions now say where to download
  the files.
- **G2. BLOCKED rows read as shopping rows. [fixed]** R-ML24 horns, the
  D85MG/R-ML24 hardware pack, and the D36V50F6 regulator now carry qty
  "0 for now" and "DO NOT BUY YET" with a pointer to where the build pauses.
  Steps 18–19 gained red SOURCING GATE banners (STEP_NOTES, rendered above the
  moves so arrow numbering is untouched); step 12 tolerates the empty 6 V
  pocket explicitly.
- **G3. Wiring chapter presented as an executable step. [fixed]** TOC and
  road-to-robot copy now say "reference maps only"; a leading wire rule states
  no step in this book cuts a wire; the meter checklist is labeled a preview;
  steps 11/15/20 no longer promise wiring-chapter actions that don't exist.
- **G4. Missing tools/consumables. [fixed]** Chapter 1 tools now include the
  P1S printer itself, an M2 driver for the head pack, a heat-set insert tip,
  grease (applied in step 18 move 5), and zip ties; the TPU tip covers drying;
  the camera row names the Pi 5 22-pin cable.
- **G5. Consistency bugs. [fixed]** Step 2 insert accounting corrected
  (20 + 27 = 47, the neck/collar 6 were missing); step 20 says "head face" vs
  "body face panel"; cover chips read AGES 10+ WITH AN ADULT and ONE SCREW
  SIZE; "one screw, one key" copy admits the pack's M2 hardware.
- **G6. Electronics table overflow. [fixed]** The taller hold rows pushed page
  1 of 2 past the footer; the split now sends one more row to page 2.

## H. Prime-time pass (2026-07-19, release `v2.0.0-prototype.4`)

A full five-reviewer audit of the 42-page book (four page-range readers plus a
computed cross-consistency check), and the chapter the goal was missing: the
guide now ends at a robot whose brain is running, not just a dry body.

- **H1. Chapter 5 was an anticlimax — and the software path was absent.
  [fixed]** "Check & play" was one page ("admire, measure, and keep the battery
  out") plus the back cover. The chapter now carries the full bring-up a builder
  can do without a single open gate: p42 runs the shipped `robotd --simulate` +
  supervision dashboard on any Mac/Linux (Python 3.11+) with a real captured
  screenshot and a four-point read of the page; p43 condenses the Pi-5 appliance
  install (flash, Tunnel, three secret files, `install.sh`, attestations,
  two-UART proof, and what the installer deliberately refuses to do); p44 seats
  the resident copilot — full Pi authority, the firmware/physical floor it
  cannot cross, the journal, a replayable `--source agent` robotctl session,
  and the honest handoff to the commissioning gates. TOC, road-to-robot strip,
  and the ch4 opener hand-off updated to match; book is now 45 pages.
- **H2. The dashboard picture is evidence, not artwork.**
  `scripts/capture_dashboard_screenshot.py` boots the real simulator +
  dashboard, replays the narrated agent session, screenshots via headless
  Chrome, and fails if the blackbox doesn't contain that exact session (or if
  port 8072 is already occupied — a stale server would silently photograph the
  wrong state). Rerun after any dashboard UI change.
- **H3. Cross-consistency audit: all computed checks pass.** Screws (43 in-step
  + 4 deferred lid corners = 47 everywhere), inserts (20 + 27 with per-step
  batches matching the joint registry), pieces (40+4+1 on 13 plates, per-part
  counts vs registry), coupons (18 tests / 19 objects / 5 plates), friendly
  names (zero fall-throughs), TOC page numbers, and the release tag/assets all
  reconcile. Two nits fixed: the tools table hardcoded "47" (now `N_SCREWS`),
  and the dashboard was missing from the release index artifact map.
- **H4. Page-audit fixes (pp. 1–11).** Rear-hero red slivers behind the motor
  wheels are now explained in their callout (they are the red motor caps);
  the cooling-vent callout dot sits on the vent slots instead of the wall;
  "only fasteners you'll buy" caption reconciled with the M2 servo-pack
  hardware (the p3 copy already was); plate-6 spares parenthetical attached to
  the washer entry instead of dangling after "tilt bushing"; plates-page caption
  grammar; hardware-pack contents no longer list a redundant bare "screws";
  the 5 V regulator row now says the part is safe to buy while its wiring
  stays blocked (it read as self-contradictory next to the 6 V hold row); the
  6 V regulator silhouette tile says "skip for now" and the matching page
  admits small buys have no tile; and the coupon project page explains the
  "Body Primary PLA" try-out plate (D034's candidate family), with an optional
  candidate-spool row added to the filament table.
- **H5. Declined:** the plate manifest's TPU role string "battery pads"
  (singular part, but the pad frame carries four cushion pads and fixing the
  string means regenerating the tracked 3MF for a noun); the cream featureless
  screw thumbnail (reads fine at GATHER size, labeled everywhere); the
  footerless full-bleed chapter openers (a deliberate hero-page design); the
  tiny blackbox text inside the dashboard screenshot (the numbered callouts
  carry the meaning).
- **H6. The L/R axis badge was mirrored — the A1 bug class in the overlay.**
  Front-facing cameras put the robot's RIGHT on the image's LEFT, but the
  badge statically read "L ← FRONT → R"; on step 7 it actively taught a 180°
  MDDS10 rotation. `robot_axis_badge()` is now view-aware per step: front
  views read "R ← FRONT · IT FACES YOU → L", the two rear-camera steps keep
  the original, and the side-view Pico step shows no L/R badge at all (its
  horizontal axis is front-back). The "Front and back" primer now teaches the
  handshake flip, and the badge trigger uses word-boundary matching (it used
  to fire on "LEFTOVERS").
- **H7. The battery never left the renders.** Step 9 is a dry fit — the book
  removes battery, clamp, and pad — but the renderer only accumulated parts,
  so steps 10–16 showed them still installed (a picture-first builder would
  leave the battery in). `render_assembly_steps_v2.py` now withdraws
  dry-fit-only parts after their step (`REMOVED_AFTER_STEP`), and every step
  render was regenerated from freshly rebuilt v2 exports (the worktree's
  stale pre-D034 exports were rebuilt first — a render from them would have
  resurrected fixed geometry). Step 12's "notch goes around the battery
  wires" is now future-tense.
- **H8. The numbered-arrow system was redesigned after all three page
  auditors flagged it.** The magenta badges numbered arrow PAIRS in scene
  order, but the anatomy page teaches numbered MOVES — so readers paired
  arrow 2 with sentence 2 and executed wrong pairings on nine pages; several
  projected landings were also geometrically wrong (dots on wheel faces,
  floors, shadow gaps, or buried under detail insets). Arrows are now
  glyphless — the unbroken line pairs a tail dot with a landing ring, so
  nothing can be read as a move number or collide with "Detail A/B" panel
  letters — and `STEP_ARROW_TWEAKS` prunes, per part name, every arrow whose
  landing the audit verified as misleading (steps 1, 3, 5, 6, 7, 9–16, 18,
  19, 20). Surviving arrows: one or two per step that land on real visible
  destinations. The anatomy page and the Build opener now state the
  convention, and the wheel-bench page gained BACK/FRONT identification
  chips (its gold insert markers had been deliberately removed when the
  insert seat moved deep into the wheel, leaving the back wheels
  unidentifiable).
- **H9. Text/diagram truth fixes from the audit.** Step 3's check no longer
  claims gearmotor shafts "spin freely" (they drag through a 99:1 gearbox —
  it contradicted step 6's motor-holds-the-wheel check) and its wire move no
  longer depends on wires the proxies don't render; step 4's port-over-well
  check is now the tactile hex-key probe; step 8 points the head-cable
  promise at step 19 (in-book) instead of "later"; step 9 admits the four
  floor pads hide behind the tower; step 15 explains the see-through light
  slots (the "mystery green square" is the interior until step 20 — truthful,
  now narrated); step 17 disambiguates the lid's two round holes (button vs
  neck); step 18's check names the neck, not an unintroduced "shoulder";
  the glow-board inset says LATER; the power-map relay row's destination is
  the coil (status moved into the middle column); the p39 diagram's
  branch-feed and motor-fuse wires are drawn RED per its own legend (they
  were blue/green/yellow); Detail B's washer is printed-cream (not
  annotation-magenta) with its 22 mm dimension spanning the washer, not the
  wheel; three inset labels got unclipped leaders; the ch5 opener ship list
  is now plain language; and the copilot page explains both drive arguments.

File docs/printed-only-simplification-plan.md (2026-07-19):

# Printed-Only Body Simplification Plan

*Dated record, written before D038 renamed the v2 "coupons" to "proofs";
historical wording retained.*

Date: 2026-07-16
Status: direction accepted — Brian approved all three recommendations on
2026-07-16 (recorded as D025/D026/D027 in the decision log) and approved
the appearance deltas the same day. Three same-day Codex review rounds
invalidated the first three packing layouts; the current box screen
(layout v5, 238 x 220 x 133 on verified datums) closes with a 2 mm margin
policy including wall margins, and the review's process asks are folded
into Phase 2's exit. Round 4 (same day) reproduced the v5 screen,
verified the corrected datums, and GREEN-LIT Phase 2 with four explicit
carry-in requirements (see the review section). The D027 packing gate
itself remains OPEN pending the v2 BREP model + inventory-driven
validator. Phase 2 is now the active work.

## Goal

Rework the v1 body so that:

1. No purchased metal structure remains — no brackets, standoffs, spacers,
   shoulder bolts, bearings, hubs, washers, or locknuts.
2. The only fastener hardware is heat-set threaded inserts and screws, in
   exactly one thread size and one length each, bought in one order.
3. The printed-part count and print-plate count drop far enough that one
   person can print and assemble the body without a spreadsheet.

Electronics, motors, servos, switches, the battery, and hardware that ships
attached to a purchased component (the E-stop nut, the relay's integral
bracket, servo horns and horn screws, connector nuts) stay. The goal governs
*structural* hardware, not the electrical BOM.

D024 already removed *custom-fabricated* metal. This plan removes the
remaining *retail* metal and collapses the fastener system.

## Where The Metal Is Today

| Item | Qty | Role | Printed replacement |
| --- | ---: | --- | --- |
| Pololu #1569 motor brackets | 2 | Primary motor retention | Tray-integrated motor saddle + bolted clamp cap; motor's own tapped M3 face holes |
| Pololu #1997 aluminum hubs (+ set screws) | 2 | Shaft-to-wheel torque | Printed wheel core with integrated 4 mm D-bore hub + one radial M3 clamp screw |
| WDS 615-M6-8-65 shoulder bolts | 2 | Front idler axle | Printed stub axle integral to the idler pod |
| 608 bearings | 4 | Front idler rotation | Printed journal + replaceable printed bushing (wear part) |
| M6 washers + prevailing-torque locknuts | 2 sets | Idler axial retention | Printed retaining cap + one M3 screw into an axle-end insert |
| goBILDA spacers + shim | 2 sets | Idler axial stack | Printed spacer features integral to axle/pod |
| Koyo 6807-2RS pan bearing | 1 | Head pan support | Printed greased journal ring + printed thrust face; bayonet retainer |
| MF84ZZ flanged bearing | 1 | Passive tilt pivot | Printed shoulder bushing |
| McMaster 92981A143 shoulder screw | 1 | Tilt pivot pin | Standard M3 screw through the printed bushing into an insert |
| M2 metal standoffs (regulators 7, amps 4, Pico 4) | 15 | Board mounting | Printed pocket-and-clamp cradles; no board screws at all |
| M3 metal spacers/standoffs (controller plate 4+4, deck 4, motor brackets 6) | 14 | Elevation | Printed towers integral to tray/plates, M3 into inserts at the top |
| M2/M2.5 screws, washers, locknuts (LEDs, camera, vent, cartridges, head panels, race rings) | ~50 | Small-part retention | Printed pegs + clamp bars/snaps; M3 where a screw survives |
| M4 bolts (Blue Sea 5045) | 2 | Fuse-block mount | Printed saddle clamps over the block's base, M3 into deck inserts |
| M5-class bolt (relay 5.4 mm hole) | 1 | Relay mount | Printed pocket keyed to the integral bracket + M3 clamp tab |
| 20 mm textile battery straps | 2 | Battery retention | Printed PETG clamp bar + printed TPU pads, 2 M3 screws |

Current fastener sprawl: five thread sizes (M2, M2.5, M3, M4, M6), two insert
sizes plus a provisional M4, roughly 30 metal standoffs/spacers in three
sizes, plus washers and locknuts. Target: one insert SKU, one screw SKU.

## The Single Fastener System

Scope (tightened after review): the M3 insert and M3 x 8 screw are the only
**separately purchased body-fastener SKUs**. Hardware that arrives with a
purchased component — servo horn screws, the E-stop and connector nuts, the
relay's bracket hardware — is exempt, requires no separate purchase, and
keeps its own parameters in the model. The validator rule is therefore "no
separately-purchased fastener other than the two SKUs," not "zero non-M3
references."

- **Insert:** M3, 4.6 mm OD x 5.7 mm long (ruthex RX-M3 class — this matches
  the existing `insert_hole_m3 = 4.6` parameter, so calibrated coupon data
  carries over). One 100-pack.
- **Screw:** M3 x 8 mm socket head cap (ISO 4762), one 100-pack. One 2.5 mm
  hex key drives the entire robot.
- Estimated usage in the reworked body: ~60-70 of each, so single 100-packs
  with spares. The M3 x 16 escape hatch remains available but any use of it
  is a deliberate D026 amendment, not a quiet second kit.

Design rules that make one length work everywhere:

1. **Standard joint:** 3.2 mm printed flange over an insert boss gives
   ~4.5 mm engagement of the 5.7 mm insert. This is the default everywhere.
2. **Counterbore rule:** any flange thicker than 3.2 mm gets a counterbore so
   the screw always sees the standard joint. No second screw length exists,
   so the model must enforce this; add a validator check that every screw
   path presents 3.0-3.4 mm of clamped material.
3. **Engagement-limit rule (inverted counterbore):** where the screw enters a
   purchased part with limited thread depth — the Pololu #4867's two M3 face
   holes — thicken the printed flange locally so protrusion stays inside the
   documented maximum depth. Verify against the Pololu drawing during
   implementation.
4. **Printed washers:** anywhere a screw head would bear on TPU or a soft
   part, a printed PETG washer strip is part of the printed inventory.
5. **Screws clamp; geometry carries load.** Torque and shear always go
   through printed keys, D-bores, tongues, dovetails, and pockets. A screw's
   only job is to keep parts seated. This is what makes plastic-thread-free,
   single-size fastening safe.

## Design Language For Purchased Parts

- **Capture, don't screw.** Every PCB (Pi 5, Pico 2, both regulators, both
  MAX98357A amps, ToF boards, NeoPixel breakouts, camera module) sits in a
  printed pocket, located by printed pegs through its mounting holes, and is
  held by a printed clamp bar or frame whose screws are standard M3 into
  inserts *beside* the board. This deletes every M2/M2.5 screw and all 15
  metal standoffs, and no board hole ever sees a thread. The MDDS10 (3 mm
  holes) may keep direct M3 screws into insert towers since that is already
  the standard size.
- **Odd mounting holes become printed features.** The Blue Sea 5045 gets two
  printed saddle clamps hooking its base; the Panasonic relay's integral
  bracket drops into a keyed pocket with one printed clamp tab; each is
  secured by standard M3 joints. The purchased part is captured
  geometrically; its 4.5/5.4 mm holes are simply unused or used as locators
  for printed pegs.
- **Snap and bayonet for cosmetic/service parts.** Vent inlay, front fascia,
  pod covers, service covers, faceplate, and diffuser carriers move to
  snap-fit with release slots (a snap coupon gates this). The head neck gets
  a printed bayonet retaining collar instead of a four-screw retainer.
  Screws remain only where a joint is structural or safety-relevant.
- **Fallback geometry is insurance — stated precisely.** Each fallback has
  a different strength, and only the first three are true drop-ins:
  - Wheel core keeps the #1997 four-hole pattern and hub recess: the
    aluminum hub bolts back in unchanged.
  - Motor saddles keep the #1569 bracket's full installation envelope per
    side — the 49 x 22 base, all three M3 tray stations, the 3 mm spacer
    stack, and screwdriver access — as a registered fit volume in the v2
    model, so the bracket bolts back in unchanged. (Round-2 review point:
    preserving the holes alone is not a drop-in.)
  - Battery bay keeps its strap channels: textile straps return unchanged.
  - Idler bushing cavity matches the 608 envelope: a 608 can replace the
    printed bushing *on the printed axle* — this is NOT the old WDS
    shoulder-bolt stack, and the printed axle remains the load path.
  - Head pan journal has NO drop-in fallback: reverting to the 6807 bearing
    means reprinting the neck carrier and journal parts from a parametric
    switch kept in the source.

## Design For Fewer Parts And Support-Free Printing (D028)

Brian's directive (2026-07-16): minimize part count and print with as few
supports as possible. These are hard, validator-enforced requirements for
the v2 model, not preferences. v1 baseline: 101 printed parts, with the
shell quadrants and head shells requiring build-plate supports per the
print manifest's own guidance.

### Part-count budget

**Hard budget: <= 40 printed parts** for the complete robot (body + head +
TPU), excluding calibration coupons and explicitly optional cosmetic
variants. The inventory manifest carries the budget and the validator
fails when it is exceeded. Every separately printed part must carry a
one-line justification for existing: service access, material/color
change, print-orientation conflict, calibration interface, or wear-part
replaceability. "It was separate in v1" does not qualify.

Merges beyond the already-planned split-system deletion:

| Merge | Saves |
| --- | --- |
| Bumper switch plates -> pockets molded into the tray underside | 6 parts, 12 inserts, 12 screws |
| Harness rails -> deck underside ribs with strap slots | 2 parts |
| Pi shelf -> one controller-tower part with the MDDS10 plate | 1 part |
| Pico mount -> tray floor bosses + one clamp bar | 1 part |
| Motor pod shrouds + service covers -> shell wheel-arch region | ~4 parts |
| Front ToF pods -> fascia pockets | 2 parts |
| Side ToF pods -> shell pockets + clamp bars | ~2 parts |
| Cable strain plate -> deck/lid feature | 1 part |
| Wheel trim rings -> deleted (optional cosmetic) | 2 parts |
| Vent inlay -> optional (the lid slots print directly) | 1 part |
| Battery TPU pads -> one TPU pad frame | 1 part |

Draft v2 inventory under the budget: body ~26-30 parts + head ~10-12
parts (the printed pan journal already deleted the v1 carrier/retainer
stack). Integration risks to confirm during BREP: switch pockets in the
tray commit the 0.4/2.0/2.4 mm bumper interface to the tray print —
acceptable because the interface coupon is calibrated before any tray
prints; if it fails on the printed tray anyway, the recovery is a shim
plate, not a redesign.

### Support-free rules (enforced by the Phase-2 overhang audit)

1. Every inventory part declares its print orientation; all audits run in
   that orientation, and the print manifest inherits it.
2. Overhang rule: no downward-facing surface beyond 50 degrees from
   vertical outside allowlisted convex-rollover regions (dome-like
   continuous perimeters, which print support-free).
3. No enclosed horizontal cavities: every internal void opens up, down,
   or through a chamfered side.
4. Interior shelves and bosses on vertical walls carry 45-degree gussets.
5. Horizontal holes <= 8 mm print as-is; larger ones become teardrops or
   are redesigned onto vertical axes.
6. Bridges <= 30 mm; flat pocket ceilings chamfer where cosmetics allow.
7. Flat parts print cosmetic-face-down on the textured PEI plate.
8. TPU parts use open cross-sections — the bumper C-halves become
   open-bottom U-profiles with zero bridged cavities.
9. Insert bosses bias to vertical axes in print orientation; a horizontal
   insert is a design smell to eliminate, not accept.
10. The support-exception list starts EMPTY. Any part that needs supports
    requires a named entry with a reason and sign-off; the target is a
    zero-support inventory.

### Orientation strategy for the major parts

| Part | Orientation | Why it prints support-free |
| --- | --- | --- |
| Tray | flat, bottom down | Motor saddles are up-opening troughs; deck towers are vertical; underside switch pockets bridge <= 22 mm |
| Shell | upright, open bottom down | Walls vertical; the 12 mm top rollover is an allowlisted convex perimeter ending <= ~70 deg with the reveal/lid covering the last approach to horizontal; fascia/arch/grille/rear openings get chamfered or arched top edges; interior bosses gusseted |
| Lid | top face down | Underside bosses face up; recesses bridge small spans |
| Bumper halves (TPU) | flat | Open-bottom U-profile, no cavities |
| Head shells (2) | open face down | Convex dome regions allowlisted; internal ledges gusseted |
| Wheels | axis vertical | Radial clamp-screw boss tear-dropped |
| Front pods | outboard face down | Integral stub axle prints vertical; axle bending stress across layers is tiny at these loads (verify in BREP) |
| Plates, deck, panels, brackets | flat | Bosses up; ribs up |

### Validator additions

- Overhang audit: per part, in its declared orientation, measure
  downward-face area beyond the threshold outside allowlisted regions;
  any hit fails.
- Bridge-span audit on flat cavity ceilings.
- Part-count budget check against the registered inventory.
- The print manifest's support field must read "none" for every part not
  on the (initially empty) exception list.

## Subsystem Plans

### Rear drivetrain

Motor saddles print as part of the tray; a clamp cap (2 M3) closes over each
gearbox, and the two motor face screws (standard M3 x 8 through a locally
thickened flange per the engagement-limit rule) take the reaction torque.
Wheel cores integrate the hub: a calibrated 4 mm D-bore transmits torque
geometrically; one radial M3 into an insert boss clamps the D-flat for axial
retention only. TPU tires unchanged.

*Deletes:* #1569 brackets, #1997 hubs, 6 spacers, 8 wheel screws, set screws.
*Gates:* D-bore coupon must hold 2x the 11 kg-cm extrapolated stall torque at
temperature without creep or slip; clamp-cap retention shake/pull test;
motor-thread engagement depth verified against the Pololu drawing.
*Policy change:* printed pods become primary motor retention (see AGENTS.md
amendments below).

### Front support

Replace the entire shoulder-bolt/bearing/spacer stack with a printed stub
axle integral to each removable pod, a printed wheel riding on a replaceable
printed bushing, and a printed retaining cap fixed by one M3 into an insert
in the axle end. Loads are small (worst case ~1 kg per wheel) and journal
surface speed at 0.35 m/s robot speed is a few cm/s — well inside greased
PETG-on-PETG territory. The bushing is the designated wear part and a
five-minute reprint.

*Deletes:* 2 shoulder bolts, 4 bearings, all goBILDA spacers, M6 hardware,
8 M2.5 race-ring screws, race rings.
*Gates:* loaded skid-turn wear test (target: no measurable slop after a
defined drag distance on carpet), axle bending check at 2x load, retention
pull test. 608-envelope fallback cavity preserved.
*Alternative (simpler still):* fixed printed skid domes — zero moving parts —
at the cost of carpet drag. See open decision 2.

### Head pan/tilt

Pan: the rotating neck rides in a printed greased journal ring with a flat
printed thrust face carrying the ~0.3 kg head; a printed bayonet collar
retains it. The D85MG has 7x margin over the computed static torque, so
journal friction is affordable. Tilt: the passive side becomes a printed
shoulder bushing with a standard M3 acting as the pivot pin into an insert;
the active side keeps the servo horn. Use the horn hardware bundled with the
servos if serviceable; otherwise the R-ML24 remains an allowed
component-integral purchase (it is part of the servo interface, like the
E-stop nut).

*Deletes:* 6807 bearing, keyed carrier complexity, MF84ZZ, shoulder screw,
four-M2.5 retainer, M2.5 yoke inserts (become M3).
*Gates:* pan wear/current test over a defined cycle count (watch servo
current rise as the proxy for friction growth); tilt backlash check;
grease selection that is PETG-safe.

### Electronics mounting (tray + deck)

The controller plate, Pico shelf, and power deck all sit on printed towers
that print as part of their parent (tray towers rise to the deck datum;
plate-to-shelf towers print with the plate). Standard M3 joints at every
tower top. All small boards move to pocket-peg-clamp cradles per the design
language. Deck keeps the relay pocket and fuse-block saddles.

*Deletes:* all 29 metal standoffs/spacers, M4 bolts, relay bolt.
*Gates:* clamp-bar coupon (board seats firmly, no PCB flex over components,
connectors reachable); deck stiffness check under wiring loads; cradle
service test — every board removable with the hex key only.

### Battery retention

Cradle features print into the tray (the tray is one piece; see below). A
printed clamp bar with printed TPU pads spans the pack on two standard M3
joints. Strap channels remain in the geometry as fallback.

*Gates:* inverted shake and 15-degree tilt-with-drop test with a mass model;
pad compression set check after a week clamped. Note the AGENTS.md policy
amendment below — retention is printed-plus-metal-screws rather than
textile straps.

### Bumper and switches

TPU carrier, 0.4/2.0/2.4 mm switch interface, and six D2HW switches are
unchanged mechanically. Switch plates keep M3 but move from nuts to inserts
in the plates. The carrier splits into front and rear C-halves joined at the
side switch plates with printed dovetail laps (TPU compliance makes the seam
non-critical), so each half prints flat on the 256 bed without the current
four-quadrant, four-low-plate system.

### Shell, tray, lid — the part-count collapse

The 57-part split contract exists only because the 300 x 220 body exceeds
the 240 mm usable bed. Two options:

- **Option A (recommended): shrink the body to a ≤238 mm footprint** so the
  shell, tray, and lid each print as one piece. The entire split system —
  four shell quadrants, four wall plates, tray halves, underside plate, nine
  backing plates, 18 pilots, lap lid, and their ~44 seam inserts — is
  deleted, not simplified. Fairings merge into the shell as sculpted
  surface. The rear three-cartridge system collapses to one rear panel
  carrying the EN2 cutout, mute cutout, and blank region (4 M3 joints).
  Cost: a full interior repack. Battery (110 mm) plus controller stack
  (~105 mm) currently spans ~243 mm end to end, so ~15-25 mm must come from
  stacking the Pi over the battery bay or deck, letting the shell grow
  ~10 mm taller, and tightening keepouts. First CAD task is a packing
  study; if it will not close at ≤238 mm, fall back to Option B.
- **Option B (fallback): keep 300 x 220, split in halves.** Shell and tray
  each become two pieces with integrated lap flanges and insert-backed M3
  joints — no separate backing plates or pilot hardware. Roughly halves the
  split part count instead of deleting it.

Either way: lid one piece (A) or two-piece lap (B); vent inlay snaps in;
head shell parts already fit the bed.

### Print-plate simplification

The implemented D034 pipeline now produces 45 printed pieces (40 functional,
four spare washers, one optional cosmetic skin) on 13 plates in seven exact
material/color groups. It derives every group from registry fields rather than
material-name special cases. Current shell/head gates are open, so those two
parts automatically join white PETG; direct panels use charcoal PLA, the
optional skin uses teal PLA, the diffusers use translucent-lime PLA, functional
PETG is white/black/red, and the three TPU plate groups remain charcoal.

## What Stays Purchased (Unchanged Policy)

Electronics and electromechanical parts: Pi 5, Pico 2, MDDS10, motors,
servos, camera, mic array, speakers, amps, ToF boards, NeoPixels, E-stop,
bumper switches, mute switch, EN2 pair, relay, fuse block, regulators,
battery, charger, wiring/connectors/zip ties (harness domain). Hardware that
arrives attached to or bundled with those parts (nuts, integral brackets,
horns, horn screws) does not count against the one-SKU fastener rule.

## Safety Policy Amendments (AGENTS.md + Decision Log)

This plan deliberately changes standing constraints; each needs an explicit
decision-log entry:

- **D025 (proposed): printed-only structure.** Supersedes "printed pods are
  removable shrouds, not primary motor retention," "plastic threads or
  friction fits must never retain the axle" (the axle cap is retained by a
  metal M3 screw in an insert; no plastic thread carries retention), and the
  metal-standoff requirements. Keeps: E-stop independence and its purchased
  nut, fail-stopped electrical architecture, no lifting by shell/head, and
  all electrical release gates. New printed structural parts get the test
  gates listed per subsystem above.
- **D026 (proposed): single fastener SKU.** M3 x 5.7 insert + M3 x 8 SHCS
  everywhere; validator enforces the 3.0-3.4 mm clamp-stack rule and the
  motor-face engagement limit.
- **D027 (proposed): one-piece body footprint** (or half-split fallback),
  superseding the 57-part split contract and the nine-plate pilot system.

Battery retention and motor retention move from "purchased metal required"
to "printed structure + metal screws/inserts, gated by the tests above."
If any gate fails, the preserved fallback geometry (the hub recess and
four-hole pattern, the full #1569 bracket installation envelope, the
608-on-printed-axle cavity, and the strap channels — see the precise
fallback list above) is the recovery path — not a redesign.

## Coupon Program Changes

Drop: 608 seat, 6807 seat/journal, Blue Sea M4 gauge (replaced by saddle-fit
gauge), M2.5/M4 insert and clearance coupons, split-pilot coupon (Option A).

Add: 4 mm D-bore torque coupon (print, mount on a motor, measure slip),
printed axle + bushing wear coupon, clamp-bar/PCB-pocket coupon (use the
Pico as the cheap test board), snap/bayonet coupon, saddle-clamp coupon for
the fuse block and relay.

Keep: M3 insert/clearance (data carries over), wall/lid-lap (Option B only),
bumper-interface, flush-fairing (deleted under Option A), TPU tire fit.

Net: seventeen coupons down to roughly eight.

## Execution Phases (revised 2026-07-16 after review)

The original order put the fastener pass before the v2 geometry existed,
which would have reworked every mount interface inside the old 300 mm body
and then thrown that detailing away. Revised order:

1. **Decisions + box packing screen.** DONE: decisions recorded
   (D025-D027); the box screen closed at layout v5 on verified datums
   after three review rounds (see review outcome above); Brian approved
   the appearance deltas 2026-07-16 (height subsequently revised
   144 -> 133 by the round-3 datum fix).
2. **v2 BREP packing model.** Build the 238 x 220 x 133 body skeleton in
   `robot_body.py` geometry: real shell/tray/lid solids, every purchased
   part from its drawing-backed envelope in the v5 layout, mount/support
   solids, wiring and service volumes (including the battery riser and
   fuse wire exit), thermal volumes, the full AI-HAT reserve, connector
   sweeps, printability checks (bed fit, orientation), and 3D CG /
   load-distribution acceptance from actual part masses. The validator
   must be **inventory-driven**: it enumerates a registered manifest of
   every purchased part and required service/thermal/harness volume with
   explicit clearance margins, so an envelope that was never registered is
   itself a failure — "passing" cannot mean "nothing I happened to model
   collided." It also enforces D028: the <= 40 printed-part budget, the
   per-part declared-orientation overhang and bridge audits, and the
   (initially empty) support-exception list. Exit — and this is the D027
   packing gate — that validator passing on the v2 model.
   Progress (2026-07-16): the registered inventory
   (`robot_body_v2_inventory.py`), the v2 model
   (`robot_body_v2.py`, 18 solids: tray with cradle/Pico
   bosses/molded-in switch pockets, shell with circular arches +
   mullioned openings + speaker ledges + ToF windows, lid with neck
   pass, TPU bumper C-halves with concealed bridges, front pods with
   vertical-printing axles, fascia and rear panels, the one-piece
   controller tower on a channeled plinth with a frame-and-crossbar Pi
   shelf, wheels, tire, and the five-part head skeleton with a domed
   cavity), and the inventory-driven validator
   (`validate_robot_body_v2.py`) are all green in dev mode. The
   validator has caught nine real design errors so far (tower
   placements x4, a battery-stop clip, the pod printing on its axle
   tip, the solid Pi shelf and floating MDDS10 plate as unprintable
   ceilings, and a mispositioned head cavity), and gained a solid-free
   thermal check plus a ring-aware bridge heuristic along the way. Update (same day, second slice): the four
   remaining estimates are eliminated (neck_drop now derives from the
   verified pan_servo_fit bbox; head_roof became the computed pan-sweep
   of the v2 head; the Pi/Pico service volumes are declared cable/tool
   specs), all six owed part merges are executed (the registry sits at
   exactly 40 parts with zero owed — the E-stop backing collar is now a
   lid-integrated boss in geometry), and the D026 fastener system is
   live: a FASTENER spec + nine-family JOINTS registry (30 screws + 30
   inserts total, all M3 x 8 into M3 x 5.7 inserts), every joint
   holding the 3.0-3.4 mm clamp stack, with modeled bosses, counterbores,
   and insert bores across the tray, shell, lid, towers, saddles,
   plinth, pods, rails, plus the motor-cap and battery-clamp solids
   (20 solids total). Validator PASSES IN GATE MODE on the encoded
   conditions (zero estimates, zero unmodeled joints). Update (third slice): harness route volumes (motor
   leads, speaker/mic feed, and the camera FPC threading east of the
   AI-HAT reserve, north of the pan servo, into the neck bore),
   connector insertion sweeps (charge plug, mute finger, E-stop slap —
   all enforced solid-free), and a screen-grade mass/CG budget
   (~3.06 kg, CG X=13 between the ±74 axles, support-polygon limits
   validator-enforced) are now registered checks, all green in gate
   mode. Encoding the sweeps surfaced finding #11: at extreme pan +
   full down-tilt the head's corner swept within -2.4 mm of the E-stop
   mushroom edge, so the E-stop moved to (59, 56), restoring 3.1 mm of
   real clearance; the head sweep is registered as four exact chord
   boxes of the r=78.7 disc. Update (fourth slice): the deck solid is
   modeled (segments with the riser notch, flanking harness ribs — the
   v1 rails as deck geometry per D028 — fuse pocket lip, counterbored
   tower joints; prints top-face-down, ribs building upward), completing
   geometry for every major structural part (21 solids). The validator
   gained solid-ownership semantics (a solid may fill its own registered
   plate envelopes). Gate mode passes with zero warnings at ~2.92 kg,
   CG X=10. Update (fifth slice): the v2 coupon program is
   live (`robot_body_v2_coupons.py`, originally 11 coupons: insert fit, the D026
   standard joint as a two-piece test, D-bore torque, axle/bushing
   wear, snap and bayonet pairs, the molded switch-pocket interface,
   tire fit, and the Pico capture-clamp pattern) and the print chain
   exports every solid in its declared pose with a manifest
   (`robot_body_v2_print.py`: 21 designs, supports "none" across the
   inventory, 11 registry parts listed pending). The BOM carries the
   two single-SKU fastener lines. Update (sixth slice): every registered part
   now has a solid (31 designs; the print manifest's pending list is
   empty). The E-stop mount panel merged into the lid — the lid itself
   is the IDEC clamp panel at 4 mm, inside the 0.8-6 clamp range, with
   the collar bore opened so the purchased nut lands on lid material —
   bringing the registry to 39 of the 40-part budget. Four clamp joint
   families were added (mic cradle, speaker clamps, ToF clamps, Pico
   clamp), taking the fastener totals to 40 screws + 40 inserts, still
   single 100-pack SKUs. Update (seventh slice): the v2 render
   pipeline produces the assembled/rear/chassis review images with the
   established concept lighting, and the 8-page v2 assembly guide
   generates from the live manifests (print inventory, joints, coupons,
   release gates) at output/pdf/codex_robot_body_v2_assembly_guide.pdf.
   Update (eighth slice): the tracked v2 Bambu
   Studio project exists (codex_robot_body_v2_p1s.3mf: 43 instances on
   13 plates in 6 filament groups, round-tripped through Bambu Studio;
   plate-filling parts take solo centered plates), and the assembly
   guide became the 25-page picture-first ages-10+ edition built from
   LEGO-style step renders with purchased-part proxies. Building the
   3MF caught design error #13 — three parts were disconnected solids
   (floating shell corner lugs under the arch openings, an unattached
   yoke, a bridgeless mic cradle) — fixed, with a permanent
   connectivity rule in the validator. Remaining before declaring
   D027: delivered-part mass updates, coupon prints, and the fresh
   external review round.
   Update (2026-07-17 closeout): D034 added the hybrid material registry
   without changing the 40-part functional budget: 40 installed pieces,
   four spare washers, and one optional PLA lid skin produce 45 print
   instances on 13 plates in seven material/color groups. The material
   evidence program now has 18 coupons. D035 replaced the head skeleton's
   prose-only load paths with the production solids: bayonet collar,
   printed pan journal/thrust face, captured D85MG, horn-driven neck,
   four-M3 yoke, active tilt drive, passive printed shoulder bushing, and
   physical stops. The model exports 32 connected designs, uses 47 standard
   M3 joints, and passes the inventory-driven gate with zero warnings at
   approximately 2.83 kg. The 38-page builder's book and all tracked review
   renders were regenerated from those manifests. The packing/CAD gate is
   therefore closed; delivered-part fit, coupons, harness/fuse details, and
   loaded motion evidence remain physical release gates rather than reasons
   to reopen the box layout.
3. **Fastener-system pass on v2.** Collapse `Params` to the single
   insert/screw spec; add the clamp-stack (3.0-3.4 mm) and
   engagement-limit validator checks; implement capture-or-M3 mounts for
   every board and purchased part. Exit: validator passes and no
   separately-purchased fastener other than the two SKUs appears in the
   model or manifests (bundled component hardware is exempt and stays).
4. **Drivetrain + front support rework.** Motor saddles/caps,
   integrated-hub wheels, printed axles/bushings. Print and pass the
   D-bore and axle coupons before full parts.
5. **Body consolidation + exports.** Merged fairings, single rear panel,
   snap vent/fascia, bumper C-halves; regenerate `robot_body_split.py`
   (mostly deletions), `robot_body_print.py`, `robot_body_coupons.py`, the
   Bambu project, and the assembly-guide inputs.
6. **Docs + guide.** Update BOM (two fastener SKUs), component-coverage
   matrix, AGENTS.md conventions (full rewrite of superseded lines), and
   regenerate the assembly guide.

Each phase ends with the full regen chain (`robot_body.py` →
`robot_body_split.py` → `validate_robot_body.py` → `robot_body_print.py` →
coupons → Bambu project) per repo convention.

## Expected Outcome

| Metric | Today | Target |
| --- | --- | --- |
| Hardware SKUs beyond electronics | ~15 (brackets, hubs, bolts, bearings, spacers, standoff/screw/insert kits, straps) | 2 (one insert pack, one screw pack) |
| Thread sizes | 5 (M2, M2.5, M3, M4, M6) | 1 (M3) |
| Screw lengths | many (kit) | 1 (8 mm) |
| Tools for body assembly | hex keys, nut drivers, wrenches | one 2.5 mm hex key + soldering iron (inserts) |
| Printed parts | 101 | <= 40 (hard budget, D028) |
| Print plates | 26 | 13 current v2 plates (seven material/color groups) |
| Parts needing supports | shell quadrants + head shells (build-plate supports) | 0 (validator-audited; empty exception list) |
| Calibration coupons | 17 | 18 evidence coupons across PETG, PLA, and TPU roles |
| Hardware cost removed | — | roughly $120-280 (brackets, hubs, bolts, bearings, spacers, kits) |

## Resolved Decisions (2026-07-16)

Brian approved all three recommendations:

1. **Footprint:** Option A — shrink to a 238 x 220 one-piece body (D027).
2. **Front support:** passive printed wheels on printed axles, with fixed
   skids as the fallback if wear tests disappoint (part of D025).
3. **Screw length:** strictly one — M3 x 8 with validator-enforced
   counterbores; M3 x 16 remains an escape hatch only if a future joint
   genuinely cannot be counterbored (D026).

## Packing Study — Review Outcome (2026-07-16)

**The first study's FEASIBLE result was false and is withdrawn.** A Codex
review found, and spot-checks against `Params` confirmed exactly:

- It claimed to use `Params` but hardcoded reduced envelopes and omitted
  the E-stop's 66 mm panel/backing (at X=92 it reaches X=125, past the
  238-body edge at 119 and the rollover-limited roof flat at ~107), the
  28 mm battery-lead corridor (reaching X≈135.5), the required AI HAT+ 2
  reserve, real Pi connector/cable service (the vertical Pi left 9.8 mm
  below the inner roof), and keepout-keepout collisions.
- Its rotated MDDS10 kept a front-facing terminal corridor, which the real
  board cannot do: rotating the long axis to Y turns the terminal short
  edge toward a side. The exact 238 mm packing chain built on that
  orientation was invalid.

The study was rewritten (`cad/python/packing_study_printed_only.py`): it now
imports `Params`, models all of the above, checks keepout-keepout pairs, and
prints every conflict. Its layout v3 closed at the box level.

**Round 2 (same day): the v3 close was also rejected, correctly.** A second
Codex review found four more omissions, all verified against the source:
the mute switch needs 26 mm body + 16 mm terminal service = 42 mm (v3
reserved 28); the fuse block's 22 mm wire-exit service was absent entirely;
the MDDS10's 10 mm airflow contract was violated by 5.8 mm under the
full-width Pi shelf; and the AI-HAT reserve is 96 x 74 x 22 per
`cad-mechanical-plan.md`, not the 85 x 60 x 18 v3 used — so v3's +10 mm
height was unvalidated. It also rejected incidental 0.1-1 mm clearances and
the unmodeled battery-to-rear-connector riser. Rebuilding with those
envelopes (and a new wheel-envelope check that caught the rear axle at X=78
poking the wheel 2 mm past the 238 shell) produced layout v4 at a computed
238 x 220 x 144.

**Round 3 (same day): v4's datums were wrong, and it was rejected too —
verified against the model itself.** The tray top is Z=49 (`body_bottom`),
not 49+8: `motor_controller_plate_bottom_z()` returns 54 (= 49 + the 5 mm
plate lift), which puts the MDDS10 thermal ceiling at 86.275, not 95.845
(the old formula also double-counted the 1.57 mm PCB — `mdds10_above_pcb`
measures from the mount plane). The pan-servo drop bottom is 131.6
(`pan_servo_fit` bounding box), not 130, and the deck plate is 102..106
(`power_deck_z` ± 2). Round 3 also found the D24V90F5's two terminal
corridors missing (the north one overlapped the D36 by 4.6 mm), the
D36V50F6's wire corridor missing (east exit leaves the body by 12.6 mm —
it now faces west), the fuse wire corridor modeled at 23 mm instead of the
full 32.5 mm block height, the floor relay undersized (modeled 42 x 20
against the real 52 x 22 bracket + body/terminal volume), and three policy
holes (allowlisted pairs could hide true overlaps; wall margins unchecked —
the deck sat 1 mm from the wall; over-broad group matching). All fixed:
overlap is now never waivable, the allowlist is exact name pairs for
margin-waiver only, and wall margins are enforced. The result is **layout
v5 at 238 x 220 x 133, closing with zero violations and no margin under
2 mm**:

| Delta | Why |
| --- | --- |
| Body grows to 238 x 220 x **133** (+12 mm vs v1's 121) | Computed on verified datums: thermal ceiling 86.275 + 4 shelf + 28 Pi + 22 HAT + 3 margin = 143.275 required pan-servo drop bottom vs the v1-derived 131.6. Offset-shelf alternatives fail at box level (over-battery evicts the deck, the fuse block's only home; a south floor shelf hits the idler pods and arch). Phase 2 note: the stacked 28+22 band is conservative — the physical HAT sits ~17 mm above the Pi PCB, so BREP with the real HAT drawing may recover ~10 mm |
| Axles pull in to ±74 (148 mm wheelbase) | Keeps both 86 mm wheels ≥2 mm inside the shell length |
| MDDS10 rotated, terminals NORTH into a side corridor; explicit 10 mm thermal volume above the board | Physically consistent orientation; frees the front X-chain; thermal contract modeled, not assumed |
| Pi 5 shelf at Z 96 (the thermal ceiling) above the controller stack, ports east; full 96 x 74 x 22 AI-HAT reserve above; Pico on a NW shelf wing | The only stack order that honors both the airflow contract and the HAT reserve |
| Fuse block owns the deck's south half, wire service overhanging the deck edge; E-stop drops through the north half at (55, 52) — entirely above the deck, no aperture needed | The 92.5 mm block + 22 mm service and the 40 mm E-stop drop cannot share a deck column; at 133 mm height the E-stop body+terminals fit fully above the 102..106 deck plate (terminals bottom 110.1) |
| Rear connectors swap: EN2 charge inlet NORTH, mute SOUTH at its full 42 mm depth | Clears the E-stop drop (north roof) and the Pi port service (east) |
| Battery mid-rear; 28 mm lead corridor ends X=113; riser channel rises through a deck notch to the EN2 | The riser volume is now modeled, with the deck notched around it |
| Relay moves to the floor, front-left; both regulators hang under the deck's east end | Deck top belongs to the fuse block and E-stop; relay keeps its terminal service volume |
| Mic offsets south to (60, -25); vent slims to a south strip; E-stop panel off-center rear-right | 76 mm mic cradle + 66 mm E-stop panel cannot both sit centered on the rollover-limited roof flat |
| Speakers move to the FORWARD side walls (X -48..22, Z 115..145) | Rear side walls now carry the fuse wire service; 6 mm printed web above the wheel arches (round-2 minimum was 5-6) |

Critical margins reported by the screen: HAT-to-servo-drop 3.3; E-stop
terminals to deck 4.1; speaker-arch web 6; rear wheel to shell 2; lead
corridor to wall 2.8. Rough CG X≈7, between the ±74 axles.

**Round 4 (same day): green light.** Codex reproduced v5, verified the
corrected datums (thermal ceiling 86.275, pan-servo bottom 131.6, deck
102..106, derived height 133), confirmed the corridor/margin/policy
behavior and the relay fit, and approved starting Phase 2 while keeping
the D027 gate itself open. Four requirements carry into Phase 2 as
registered inventory obligations:

1. Register the Pico USB and SWD service corridors — done immediately at
   box level (v5.1): the former NW-wing placement put the USB corridor
   into the front bay, so the Pico moved to the floor NE quadrant with an
   east-facing USB corridor and top-access SWD volume.
2. Model the battery's real support padding and clamp geometry — the
   3 mm pad lift is now in the screen (pack top 79); the printed clamp
   bar joins the BREP model.
3. Represent the relay as separate 52 x 22 bracket, 26 x 22 body, and
   terminal-service volumes — done in v5.1; location unchanged.
4. Any height recovery from the real AI-HAT drawing is a BREP-discovered
   bonus, never an assumed reduction — 133 stands until the v2 model
   proves otherwise.

**This box screen is evidence of viability, not a gate pass.** The D027
packing gate stays open until the v2 BREP packing model — real curved shell
interior, mount/support solids, full harness routes, connector sweeps, and
CG from actual part masses — passes the inventory-driven production
validator (Phase 2). Fallback remains Option B (300 x 220 half-splits) if
BREP detailing breaks these margins.

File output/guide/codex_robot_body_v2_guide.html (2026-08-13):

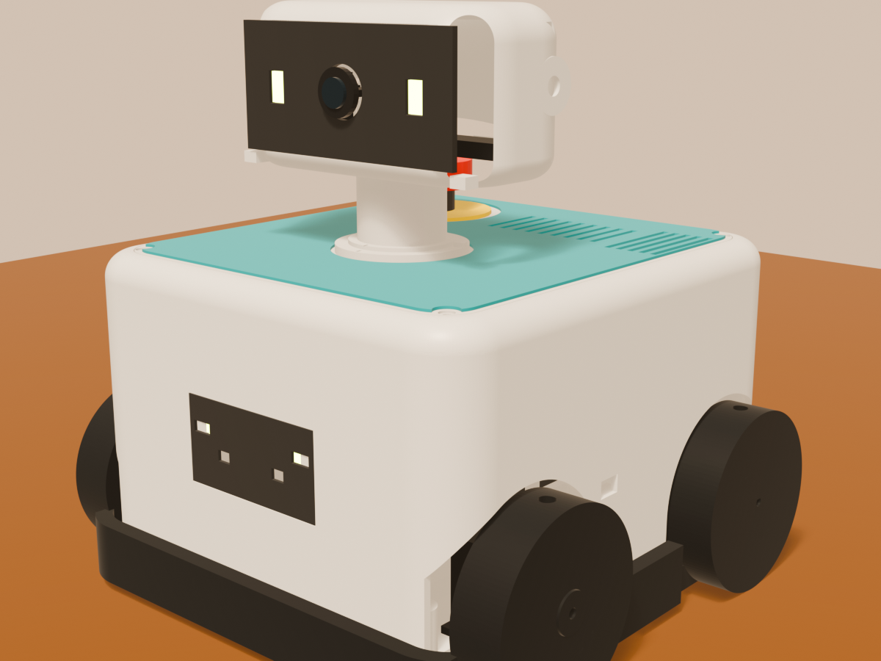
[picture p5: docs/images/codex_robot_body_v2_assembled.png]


A prototype print-and-build preview

DO NOT USE FOR POWERED MOTION

# CODEX ROVER BEAN

The Robot Body Builder’s Book

Review the geometry, print proofs, and dry-build the released chassis steps.
Bench software/firmware and evidence runners ship; production wiring, powered outputs, head physical qualification, and signed commissioning remain open.

AGES 10+ WITH AN ADULT40 FUNCTIONAL + 4 SPARE + 1 OPTIONAL13 PLATESONE SCREW SIZE

1Shopevery spool, screw, and circuit board4

2Printprototype plates, test parts, and a piece check8

3Buildtwenty steps from flat tray to finished body16

4Wirereference maps only — the harness is not released yet37

5Check & playwake the brain, meet your copilot41

BODY V2 · ZERO SUPPORTS · 51 SCREWS, ONE SIZE

Meet your robot

## This is Rover Bean



1

2

3

4

5

From the front

1The head — camera in the middle, glowing eyes beside it. It nods and turns to look at you.

2The white PETG lid carries the red button and head. The teal PLA skin above it is optional decoration.

3Face panel — two distance eyes low, glowing status bars above.

4Soft bumper — a squishy ring that feels walls and tells the robot to stop.

5Four wheels with grippy printed tires. The back pair are the motor wheels.

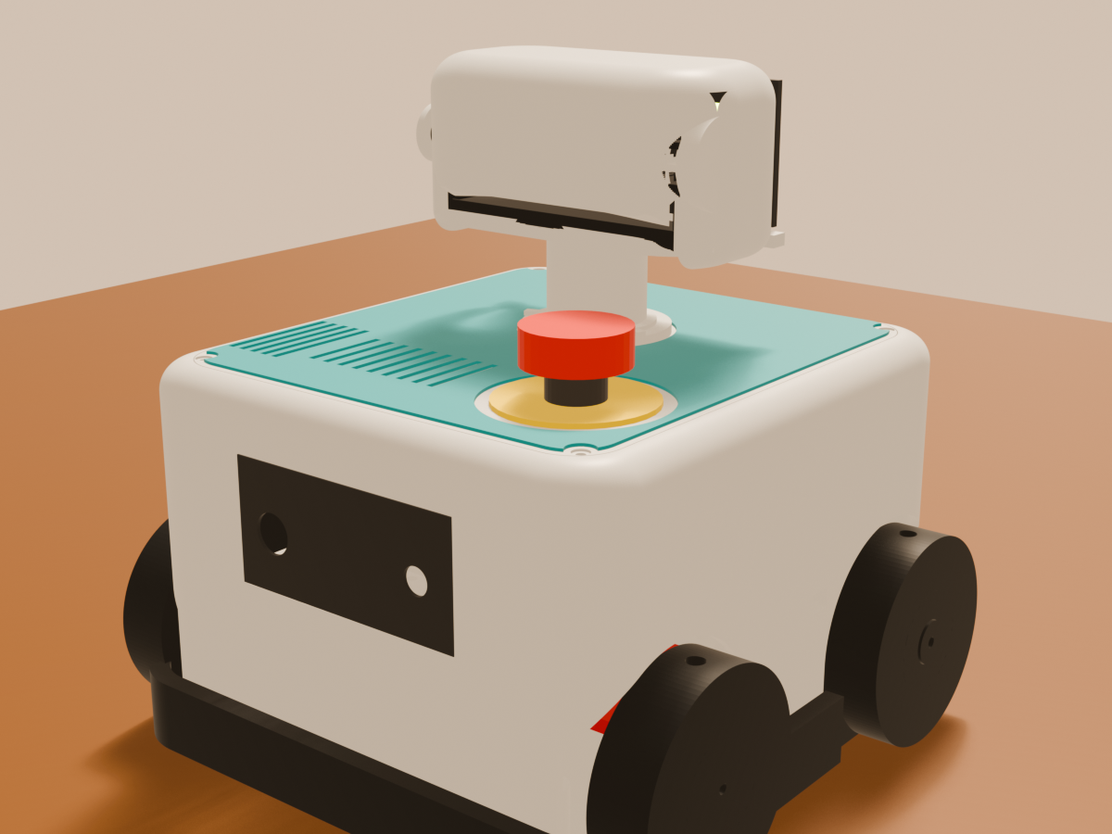
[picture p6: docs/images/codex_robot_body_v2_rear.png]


1

2

3

4

From the back

1Cooling vents — warm air from the computer leaves here.

2The BIG RED BUTTON. Push = everything stops; twist to release.

3The charging plug and the mic mute switch bolt into these two holes.

4Motor wheels. Each one has its own motor and its own speed sensor — the sliver of red behind the wheel is its motor cap.

45

printed incl. spare + optional

51

screws, one size

13

printer plates

0

supports needed

Codex Rover Bean · Builder’s BookPage 2 of 45

How this book works

## Four things to know before you build

7

## Every step looks like this

STEP 7 OF 20

GATHER

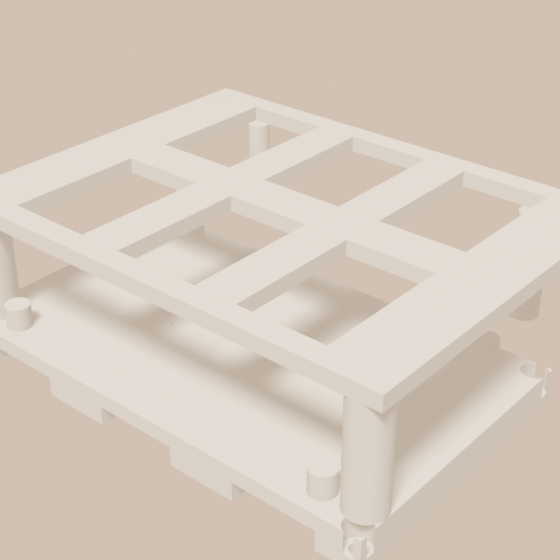
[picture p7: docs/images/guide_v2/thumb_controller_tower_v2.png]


×1brain tower

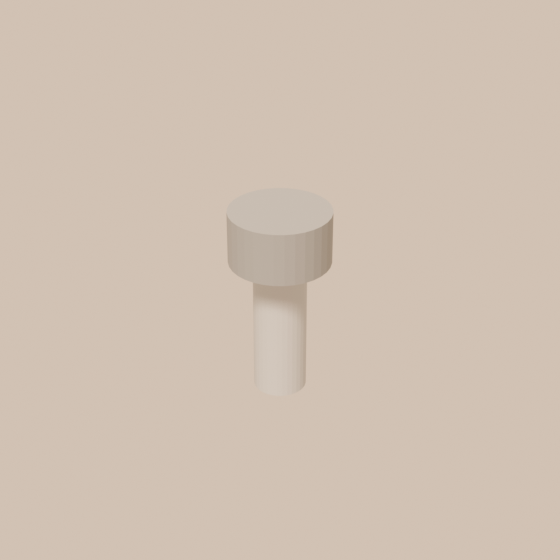
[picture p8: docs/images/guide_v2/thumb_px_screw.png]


×4M3 screws

↙ FRONT

THE BIG PICTURE

1. Numbered moves…
2. …if you want words too.

CHECK A 10-second test.

The tan GATHER strip lists every part and screw the step needs — lay them out like a cooking show. The picture shows the robot so far, with the new parts floating just off their spot; a magenta arrow slides a floating part into its landing ring. The FRONT tag points at the robot’s face.

### 1. The pictures do the talking

Match the big picture, then read the numbered lines if you want words too. Do the little green CHECK before moving on — if it fails, fix it now, because later steps cover things up.

### 2. One screw. One key.

Every screw in this robot is the same M3 × 8 screw, and one 2.5 mm hex key turns them all — the only other fastener anywhere is the tiny spline screw that comes in each servo’s own bag. “Snug” means: stop when it stops, then an eighth of a turn. Plastic hates gorillas.

### 3. Front and back

The FRONT is where the face panel and head look. The BACK has the charging plug, the mute switch, and the motor wheels. Left and right are always the robot’s left and right, not yours — and most pictures FACE the robot, so its R sits on your left, like shaking hands. The corner badge on those pictures spells out the flip.

### 4. Go in order

The steps nest like LEGO bags: wheels before shell, shell before lid. The soldering iron and the multimeter each come out for their own steps — the book tells you exactly when.

THE ROAD TO A ROBOT

1 · SHOP

buy the box

→

2 · PRINT

13 plates

→

3 · BUILD

20 steps

→

4 · WIRE

reference maps

→

5 · PLAY

brain on, motors off

Codex Rover Bean · Builder’s BookPage 3 of 45

SHOP

Chapter 1 · Shop

## Go shopping: plastic, screws, tools

### Filament (for the printer)

Filament | How much | What it becomes
White PETG | one 1 kg spool; confirm the slicer estimate | white general and enclosure-fallback structure (5 plates).
Black PETG | a small spool or known-good leftovers | black motion and wear structure (1 plate).
Red PETG | a small spool or known-good leftovers | red battery, safety-board, and motor retainers (1 plate).
Charcoal PLA | a small spool or known-good leftovers | direct visible cosmetic parts; physical fit/temperature gates open (1 plate).
Teal PLA | a small spool or known-good leftovers | direct visible cosmetic parts; physical fit/temperature gates open (1 plate).
Translucent lime PLA | a small spool or known-good leftovers | light diffusers; optical/thermal gates open (1 plate).
Charcoal TPU 95A | one 500 g spool | tires, bumper halves, battery pads (3 plates).
Candidate body-color PLA (optional) | one spool per color you audition | Proof try-out only: the shell/head color you hope to qualify. Those parts print white PETG until a candidate passes its recorded checks.

### The only two fastener packs

Fastener | Buy | Why
M3 × 8 mm socket head screws | one 100-pack | The ONLY screw in the robot (51 used + spares).
M3 × 5.7 mm brass heat-set inserts (4.6 mm OD) | one 100-pack | The only insert (51 used + spares).

Get a spares box. A cheap compartment box keeps screws, inserts, washers, and every printed spare sorted through the whole build. Future-you says thanks.

### Tools

Tool | Job
Bambu Lab P1S printer (0.4 mm nozzle, Textured PEI plate) | Prints all 45 pieces. Every plate file in this book is laid out for this exact printer and Bambu Studio — other printers mean re-slicing on your own.
2.5 mm hex key | Turns all 51 M3 screws — every screw you buy for this robot.
Soldering iron + heat-set insert tip | Melts the brass inserts into the plastic at about 220 °C. The insert tip keeps them straight — a bare conical tip loves to tilt them.
PTFE or silicone grease (small tube) | One doser-scoop on the neck’s journal and thrust faces in step 18 — the printed doser’s little bowl IS the right amount. One tube outlasts the robot.
Printed insert jigs + grease doser (free — you print them) | Three funnel jigs hold every brass insert perfectly square while the iron presses, and the doser scoops exactly one neck-greasing. They export with the proofs from the release’s tools folder — print them with your first PETG plate.
Zip ties (2.5 mm) | Tie the future harness at every printed tie point — the wiring chapter shows where.
Small flush cutters / scissors | Trims zip ties and TPU strings.
Painter’s tape + marker | Label wires as you go.
Multimeter | Checks every circuit before the battery ever goes in.

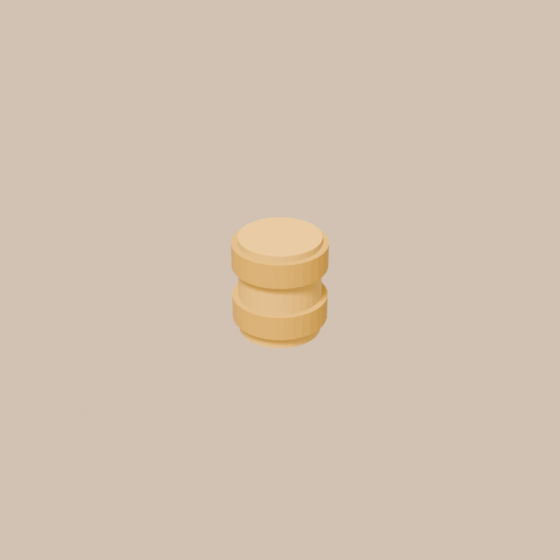
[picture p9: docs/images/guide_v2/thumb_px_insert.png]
 

This screw and this brass insert are the only fasteners you’ll buy on their own for the whole robot — everything else a step needs ships in a component’s own box. When a step says “2 screws,” it always means these.

Codex Rover Bean · Builder’s BookPage 4 of 45

SHOP

Chapter 1 · Shop

## Go shopping: the electronics box (1 of 2)

Every production component must ultimately be a normal buy-one-online part in the US. Rows marked DO NOT BUY YET or not released are decisions to close, not shopping instructions — skip them and the book tells you where their build steps pause. The nominal 28-route harness traveler ships with this version; exact terminals, measured lengths, crimp tooling, and fuse values remain open.

Part | Qty | What it does
Raspberry Pi 5 (8 GB) | 1 | The robot’s computer.
32 GB+ A2 microSD card | 1 | The computer’s memory card — the robot’s programs live here.
Raspberry Pi Camera Module 3 Wide + Pi 5 camera cable (22-pin, 300 mm) | 1 | The robot’s eye. The Pi 5 uses the small 22-pin camera connector — the 15-pin cable in the camera box fits older Pis, not this one.
Raspberry Pi Pico 2 (no headers, no WiFi) | 1 | The safety helper: reflexes and watchdog.
Cytron MDDS10 motor driver | 1 | The purple board that powers the wheels.
Pololu #4867 gearmotor (99:1, 25D, 12 V, encoder) | 2 | The wheel motors.
Hitec D85MG servo | 2 | The neck motors (look left/right, up/down). The single arm, spline screw, grommets, and eyelets in each servo's own bag are the drive parts — the old metal-horn and hardware-pack rows are retired (D048), so there is nothing extra to buy. Confirm the delivered arm against the horn-capture proof before the head steps.
Bioenno BLF-1203AB 12 V 3 Ah LiFePO4 battery | 1 | The robot’s power pack.
Bioenno BPC-1502DC charger | 1 | The matching charger. Only ever use this one.
Switchcraft EN2P3M20 inlet + EN2C3F20G2 plug | 1 pair | The keyed charging plug on the back.
Pololu D24V90F5 regulator (5 V) | 1 | Safe to buy — the settled pick, and since D053 it feeds the head servos too (the separate 6 V rail is retired; its deck bay stays as a reserved spare). What stays BLOCKED is wiring it: the novice-safe locking Pi input, backfeed protection, downstream fusing, boot/load margin, thermal proof, and the shared-rail servo-transient bench test are open; never feed the GPIO header from this preview.
Panasonic CB1A-R-M-12V relay | 1 | The motor power switch the red button controls.

Codex Rover Bean · Builder’s BookPage 5 of 45

SHOP

Chapter 1 · Shop

## Go shopping: the electronics box (2 of 2)

The rest of the electronics box:

Part | Qty | What it does
Production relay driver | not released | BLOCKED, but the candidate is selected (D054): the fixture's Adafruit 5648 MOSFET driver, promoted from negative-control duty. Exit: positive-control conditioning, fit, and EE review — one bench session with a part already in the fixture box.
Pico-local physical reset | not released | BLOCKED, but the candidate is selected (D055): a seventh Omron D2HW — the same switch the bumpers already trust — recessed behind a printed guard in the rear service corridor. Exit: conditioning circuit + CAD pocket.
Blue Sea Systems 5045 fuse block | 1 | Splits power safely into fused branches. D058 proposes replacing it with two sealed inline ATO holders now that the 6 V branch is retired — hold this purchase if you want to wait for that decision.
ATO/ATC fuse assortment box | 1 | Buy the cheap assortment; INSTALL NOTHING. Every value stays a release gate until measured load, conductor, inrush, time-current, selective-clearing, and thermal evidence is reviewed — owning fuses is harmless, installing unproven values is not.
IDEC XW1E-BV402M-R emergency stop | 1 | THE BIG RED BUTTON.
E-Switch PVB3F230SS311 mute switch | 1 | The microphone privacy switch (glows red when muted).
Omron D2HW-C202MR bumper switches | 6 | Feelers inside the bumpers.
VL53L1X time-of-flight boards (Adafruit 3967) | 2 (+2 optional) | Distance eyes. Two in front are the baseline; the side pair is optional garnish (D057) — the bumpers are the safety floor and the camera is the perception plan. The side windows and clamps stay in the prints either way.
Adafruit 5975 NeoPixel breakouts + JST-SH cables | 4 | The glowing eyes and status lights.
USB microphone (any small one to start; ReSpeaker array as the upgrade) | 1 | The robot's ears. Any plain USB mic clears bring-up (D060); the ReSpeaker array slot remains for when the voice software earns it — its exact revision plus the true VBUS-cut/no-backfeed mute interface remain BLOCKED either way.
Enclosed 3 W 4 ohm speakers + 2× Adafruit MAX98357A amps | 1 set | The robot’s voice.
Harness bench stock (WAGO 221-412/415 lever nuts, label tape, wire in the traveler's published gauges) | 1 set | Safe to buy under the D047 termination policy — lever nuts are already trusted fixture hardware. Owning stock is not wiring: the battery stays out and nothing gets crimped until the release below.
Production terminals + measured cut list | not released | The exact terminal schedule, measured lengths, and the one named crimper are still open; do not improvise a powered harness from this preview.

Codex Rover Bean · Builder’s BookPage 6 of 45

SHOP

Chapter 1 · Shop

## Match the electronics before they enter the robot

Use these silhouettes to sort the big purchased parts. They show identity and connector direction, not exact scale; small buys (memory card, charger, plugs, glow boards) go by their bag labels, and the delivered-part fit record still decides whether a component passes.

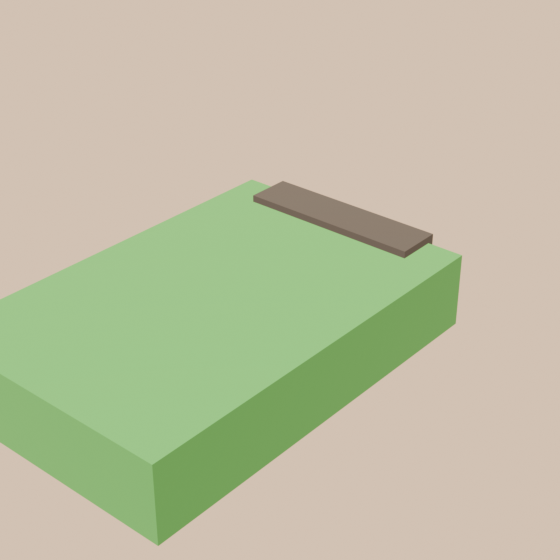
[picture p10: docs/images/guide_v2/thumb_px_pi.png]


Raspberry Pi 5

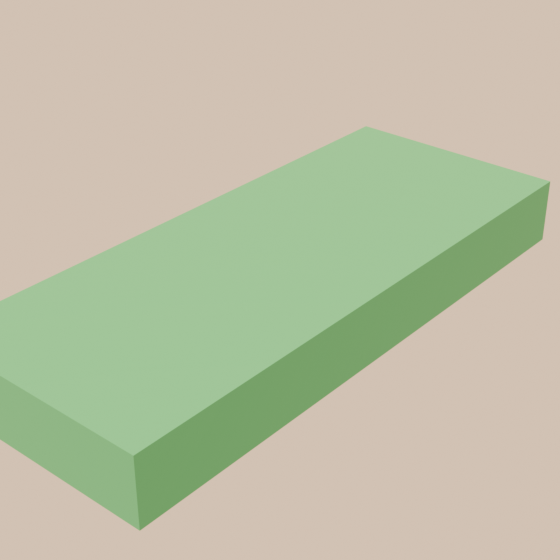
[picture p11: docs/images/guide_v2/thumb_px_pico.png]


Pico 2

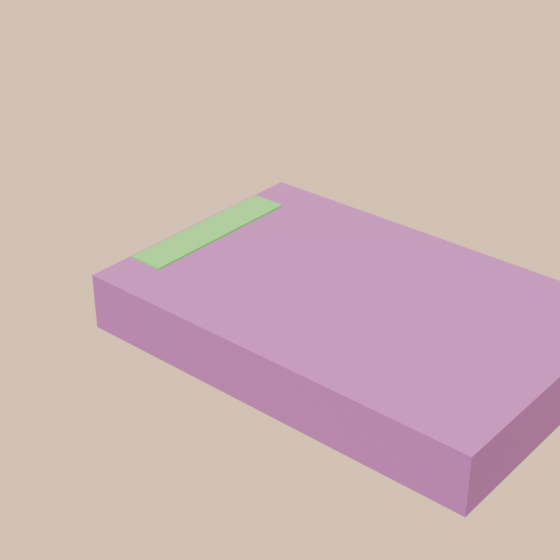
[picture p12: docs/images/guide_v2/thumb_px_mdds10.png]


MDDS10

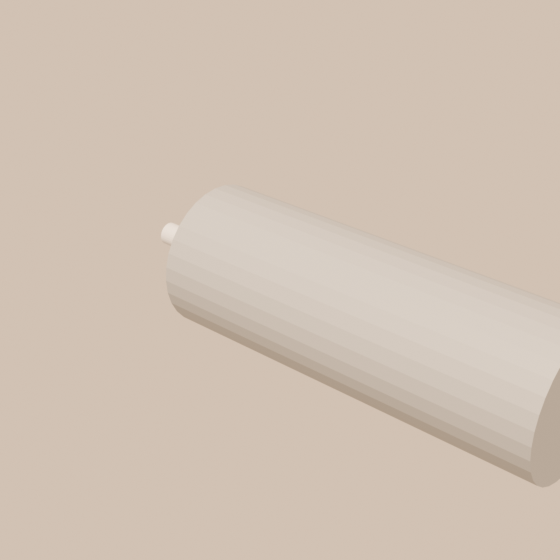
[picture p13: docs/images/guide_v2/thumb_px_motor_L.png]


25D motor ×2

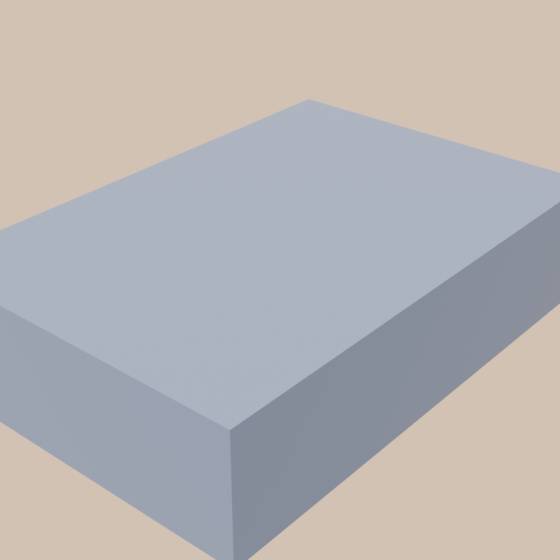
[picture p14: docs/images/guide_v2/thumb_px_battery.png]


Bioenno battery

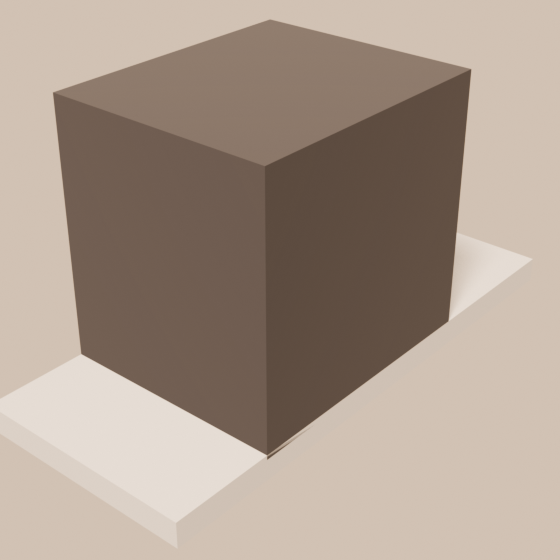
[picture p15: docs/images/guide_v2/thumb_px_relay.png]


Panasonic relay

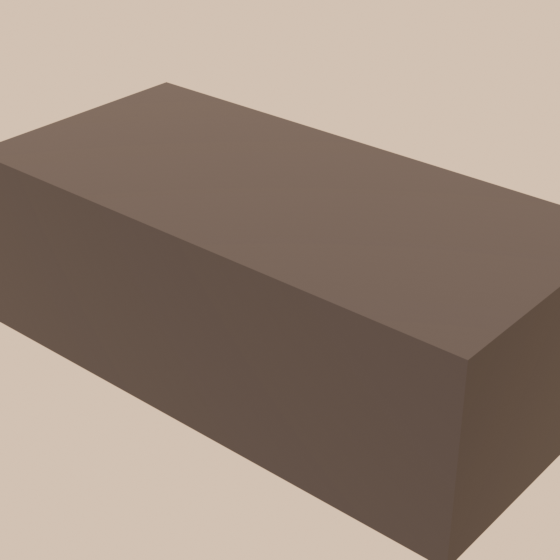
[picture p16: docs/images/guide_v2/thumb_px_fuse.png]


Blue Sea fuse block

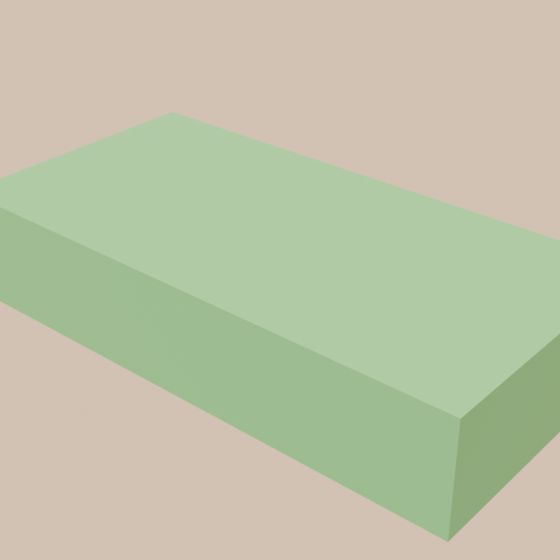
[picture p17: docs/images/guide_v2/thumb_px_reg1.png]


5 V regulator

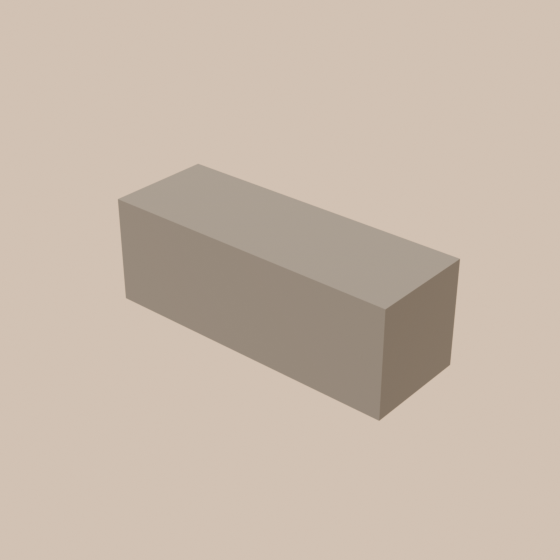
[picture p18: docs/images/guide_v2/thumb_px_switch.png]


Bumper switch ×6

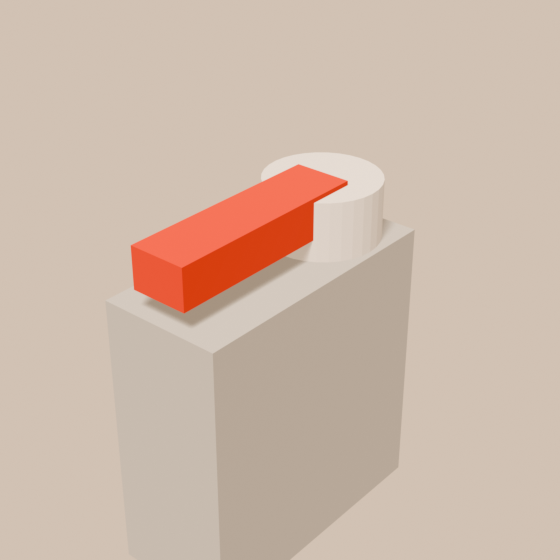
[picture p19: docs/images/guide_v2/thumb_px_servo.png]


D85MG servo ×2

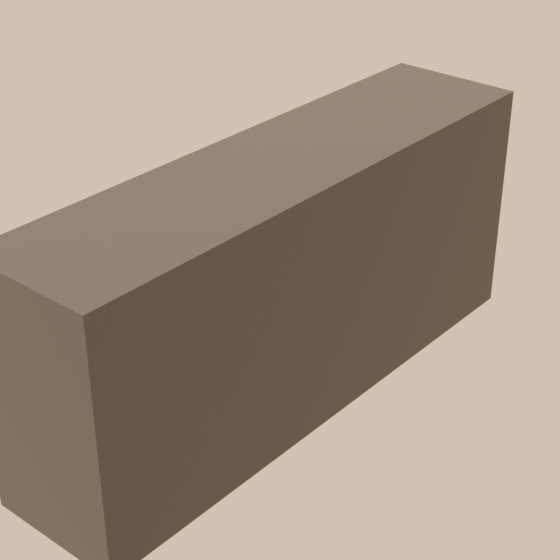
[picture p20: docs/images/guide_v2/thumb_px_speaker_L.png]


Speaker + amp ×2

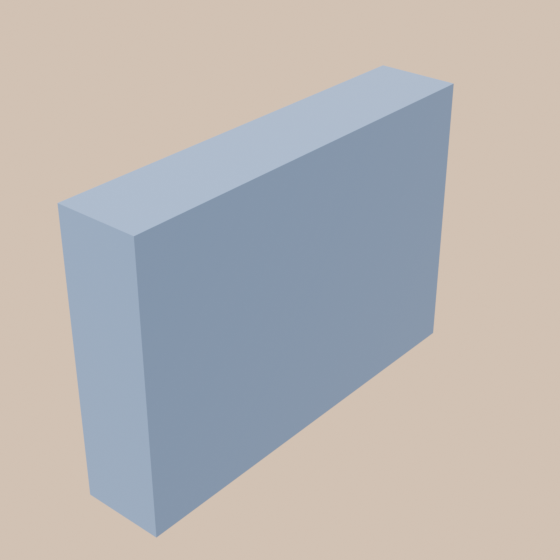
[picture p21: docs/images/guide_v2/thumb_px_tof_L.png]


ToF board ×4

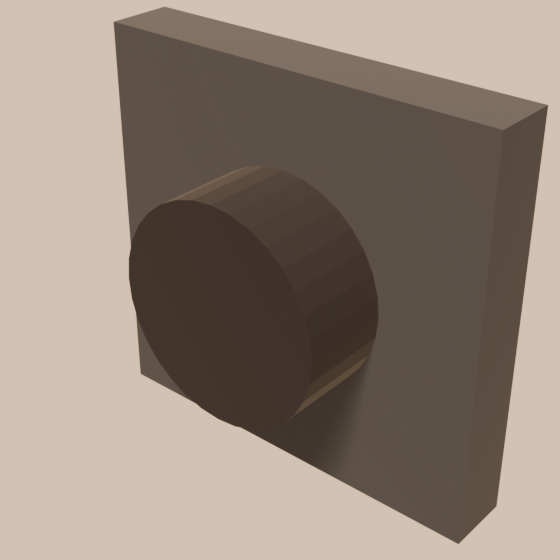
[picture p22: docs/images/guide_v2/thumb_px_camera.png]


Camera 3 Wide

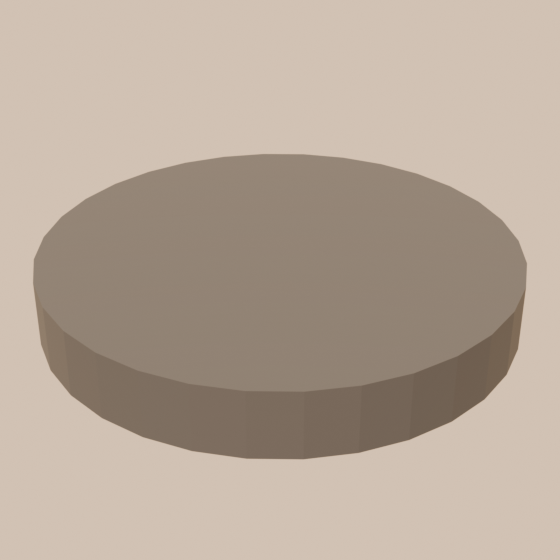
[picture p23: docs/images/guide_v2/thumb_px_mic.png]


ReSpeaker mic

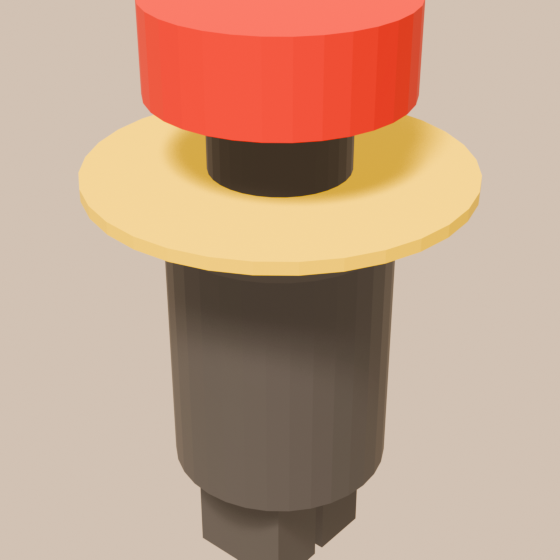
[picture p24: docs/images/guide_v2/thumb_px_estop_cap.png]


IDEC E-stop

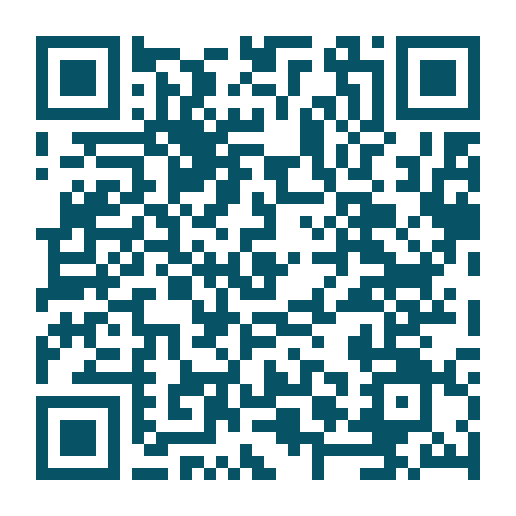
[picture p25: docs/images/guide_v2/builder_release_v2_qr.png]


One source, one version: scan for the permanent Builder Release v2.0.0-prototype.5. Download both 3MF print projects and this PDF there — plus the exact BOM, software paths, bench commands, and every open physical gate.

Codex Rover Bean · Builder’s BookPage 7 of 45

PRINT

Chapter 2 · Print

PROTOTYPE PLATES — PHYSICAL RELEASE GATES OPEN

## Print it with Bambu Studio

1

### Download, then open the prototype project

Download codex_robot_body_v2_p1s.3mf from the Builder Release (scan the QR on the previous page, or github.com/brianpattison/robot) and open it in Bambu Studio. Its 13 plates are laid out for geometry review on a P1S with a 0.4 mm nozzle and Textured PEI plate; physical release gates remain open.

2

### Load the exact family + color

Each plate names one material and one theme color. Never substitute PLA for a white/black/red PETG plate just to preserve the palette.

3

### No supports

Every part targets zero supports. If the slicer asks for supports, stop and re-check the source, plate, and declared orientation.

4

### TPU is slow and squishy

Print the tire and bumper plates slowly (the profile already does this). TPU that has lived outside its bag needs a night in a filament dryer first — damp TPU prints stringy foam.

5

### Big flat parts stay put

The tray, shell, lid, skin, and bumper plates use lots of bed. Clean the plate with dish soap first so they stick.

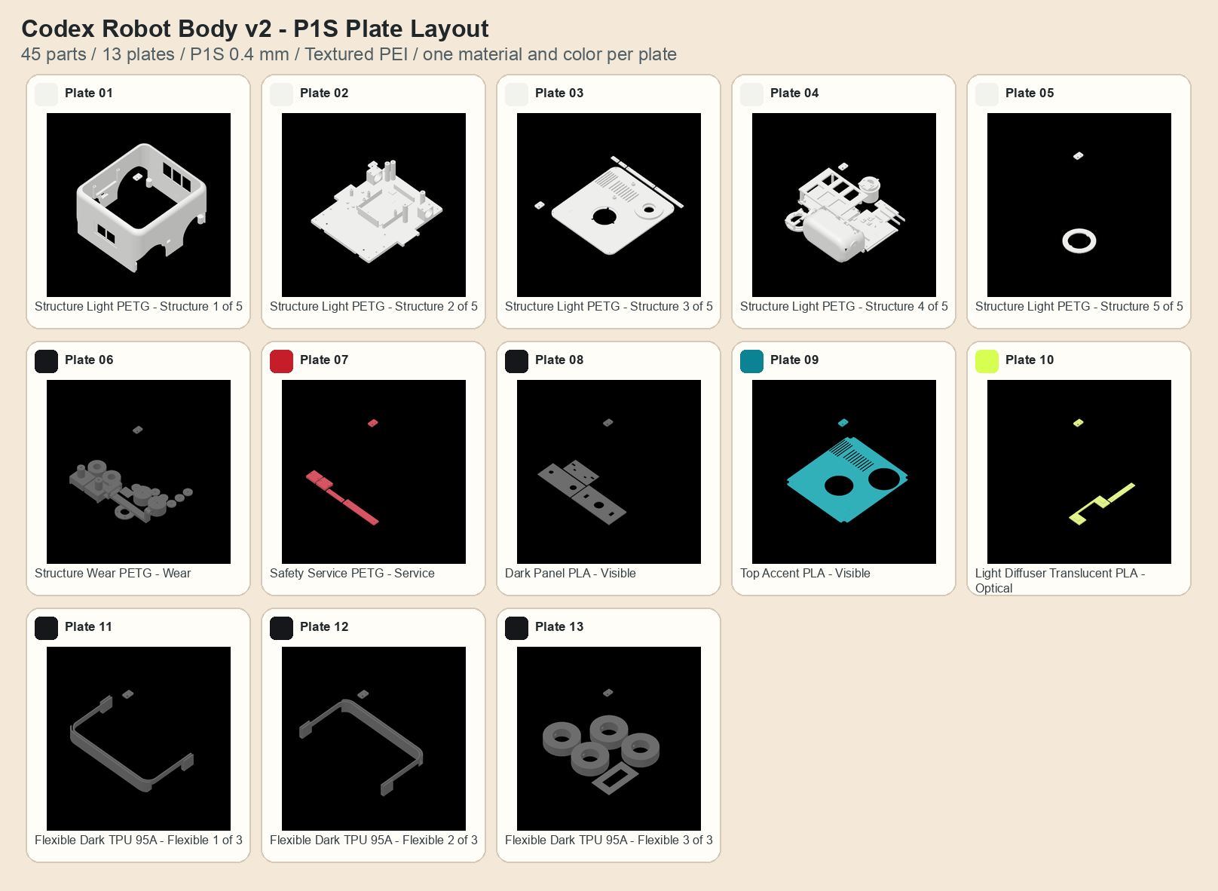
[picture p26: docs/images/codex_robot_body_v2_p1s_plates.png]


All 13 prototype plates, exactly as they open in Bambu Studio. The layout is print review, not a powered-motion release.

PRINTING ORDER

TEST PARTS

18 proofs first

White PETG

5 plates

Black PETG

1 plate

Red PETG

1 plate

Charcoal PLA

1 plate

Teal PLA

1 plate

Translucent lime PLA

1 plate

Charcoal TPU 95A

3 plates

Codex Rover Bean · Builder’s BookPage 8 of 45

PRINT

Chapter 2 · Print

## The 13 prototype plates, in printing order

# | Plate (load this filament) | Parts | What’s on it | Plan for*

1 | Structure Light PETG · Structure 1 of 5 | 1 | body shell | ≈188 g ≈4.5 h
2 | Structure Light PETG · Structure 2 of 5 | 1 | floor tray | ≈234 g ≈6 h
3 | Structure Light PETG · Structure 3 of 5 | 5 | lid, speaker clamp ×2, sensor clamp ×2 | ≈102 g ≈2.5 h
4 | Structure Light PETG · Structure 4 of 5 | 5 | head shell, power deck, brain tower, neck collar, neck | ≈170 g ≈4.5 h
5 | Structure Light PETG · Structure 5 of 5 | 1 | mic cradle | ≈5 g ≈0.5 h
6 | Structure Wear PETG · Wear | 15 | head yoke, front pod (L), front pod (R), front wheel ×2, back wheel ×2, pan slot cover, washer ×6 (the robot uses 2 — the rest are spares), tilt bushing | ≈138 g ≈3.5 h
7 | Safety Service PETG · Service | 4 | battery clamp, safety-board clamp, motor cap ×2 | ≈9 g ≈0.5 h
8 | Dark Panel PLA · Visible | 3 | head face, back panel, face panel | ≈17 g ≈0.5 h
9 | Top Accent PLA · Visible | 1 | optional lid skin | ≈21 g ≈0.5 h
10 | Light Diffuser Translucent PLA · Optical | 2 | eye light bar, status light bar | ≈4 g ≈0.5 h
11 | Flexible Dark TPU 95A · Flexible 1 of 3 | 1 | front bumper | ≈34 g ≈2 h
12 | Flexible Dark TPU 95A · Flexible 2 of 3 | 1 | back bumper | ≈34 g ≈2 h
13 | Flexible Dark TPU 95A · Flexible 3 of 3 | 5 | battery pad, tire ×4 | ≈320 g ≈20 h

The whole job plans at ≈1,276 g and ≈47.5 printer-hours — *planning estimates from the exported geometry; your slicer’s numbers win. Print each material group back to back and label its box. Every plate carries a corner check tab: test its insert bore and screw hole before the next plate; if either is off, fix the printer first.

Codex Rover Bean · Builder’s BookPage 9 of 45

PRINT

Chapter 2 · Print

## Cut-apart labels for the parts boxes

Cut on the dotted lines and tape each label to its box as a plate finishes. Keep failed/reprinted pieces outside the counted box so the Chapter 3 gather strips stay honest.

PLATE 1

Structure Light PETG - Structure 1 of 5

1 printed piece

PLATE 2

Structure Light PETG - Structure 2 of 5

1 printed piece

PLATE 3

Structure Light PETG - Structure 3 of 5

5 printed pieces

PLATE 4

Structure Light PETG - Structure 4 of 5

5 printed pieces

PLATE 5

Structure Light PETG - Structure 5 of 5

1 printed piece

PLATE 6

Structure Wear PETG - Wear

15 printed pieces

PLATE 7

Safety Service PETG - Service

4 printed pieces

PLATE 8

Dark Panel PLA - Visible

3 printed pieces

PLATE 9

Top Accent PLA - Visible

1 printed piece

PLATE 10

Light Diffuser Translucent PLA - Optical

2 printed pieces

PLATE 11

Flexible Dark TPU 95A - Flexible 1 of 3

1 printed piece

PLATE 12

Flexible Dark TPU 95A - Flexible 2 of 3

1 printed piece

PLATE 13

Flexible Dark TPU 95A - Flexible 3 of 3

5 printed pieces

CHECK All 13 boxes are labeled, and their piece totals match the plate manifest before assembly starts.

Codex Rover Bean · Builder’s BookPage 10 of 45

PRINT

Chapter 2 · Print

FIRST PRINT: QUALIFICATION PROOFS

## Open one file. Print the evidence first.

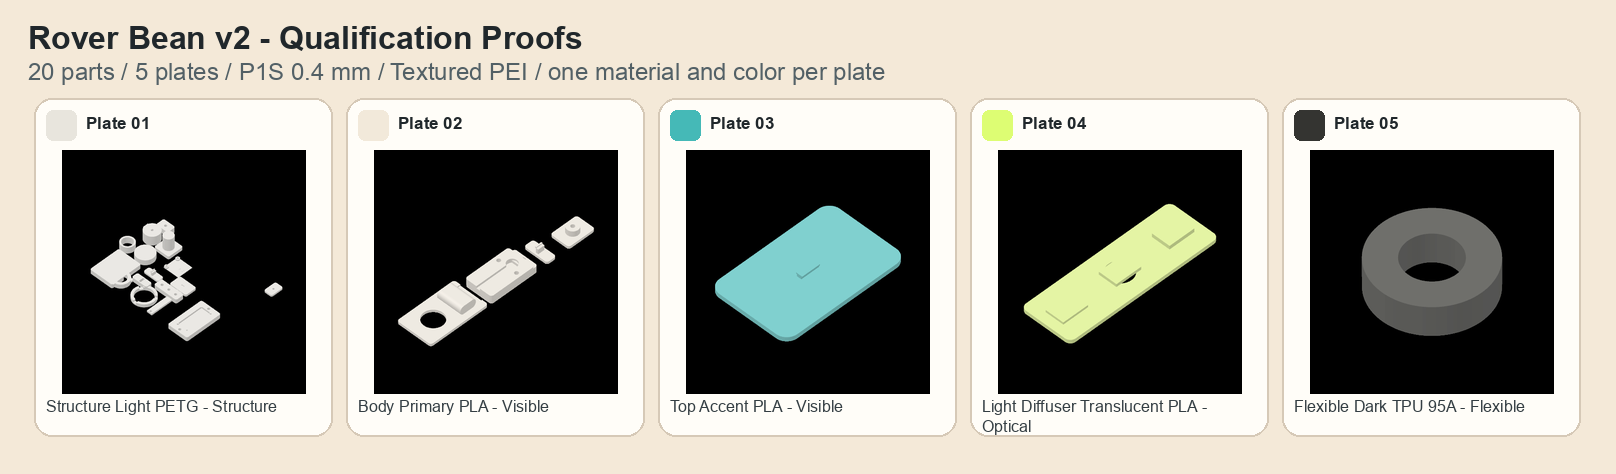
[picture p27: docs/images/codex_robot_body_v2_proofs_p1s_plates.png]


18 logical tests, 20 printable objects, 5 material-separated P1S plates. The tire ring and core are separate objects.

### codex_robot_body_v2_proofs_p1s.3mf

1. Open the tracked proof 3MF in Bambu Studio.
2. Load the exact filament product and color you intend to use.
3. Print one material plate at a time; do not substitute a pass from another spool family.
4. Run the matching fit, load, wear, heat, or optical check on the next two pages.
5. Record the machine, filament, settings, measured result, tester, and date. Blank means OPEN.

About the “Body Primary PLA” plate: that one is the try-out plate — print it in the body-color PLA you hope to use for the shell and head. Until a candidate passes every check, those parts print in white PETG (this book’s plates already do), so the try-out spool is a color audition, not a shopping-list item.

CHECK Every proof object is present, each plate contains one material/color, and no support is enabled.

Codex Rover Bean · Builder’s BookPage 11 of 45

PRINT

Chapter 2 · Print

## Print the little test parts first (1 of 2)

Print them from codex_robot_body_v2_proofs_p1s.3mf. These checks prove the shared screw, wheel, switch, board, and motion interfaces.

Test part | Filament | What it proves
Insert fit proof_insert_m3.stl | PETG | Melt one insert into each of the three holes. The one that sits flush without squeezing out goo is your printer’s perfect fit.
Screw joint proof_joint_flange.stl | PETG | Screw the small plate onto the block with one screw. It should pull down tight with no wobble and no cracking.
Screw joint partner proof_joint_boss.stl | PETG | The partner block for the plate test above.
Wheel grip proof_dbore_torque.stl | PETG | Push this onto a motor shaft and twist HARD — twice as hard as driving ever will. If it never slips, wheels are safe.
Axle spin proof_axle_stub.stl | PETG | Spin the ring on the peg a few hundred times with some pressure. It should stay smooth, not sloppy.
Axle spin ring proof_bushing_ring.stl | PETG | The spinning ring for the peg test above.
Snap click proof_snap_pair.stl | PETG | Click the two pieces together and apart ten times. The little hook must survive and still hold on.
Bayonet twist proof_bayonet_pair.stl | PETG | Twist the ring onto the stub a quarter turn — it should lock with a nice click and not pull straight off.
Switch pocket proof_switch_pocket.stl | PETG | Seat one bumper switch in the pocket: it must click when pressed and spring back, never jammed.
Tire stretch proof_tire_fit_core.stl + proof_tire_fit_ring.stl | TPU+PETG | Stretch the mini tire onto the mini wheel. Snug and even = your big tires will fit too.
Board clamp proof_pcb_clamp.stl | PETG | Rest the little green safety board on the pegs and screw the bar over it. Held gently, nothing bending.
proof_horn_capture proof_horn_capture_cradle.stl + proof_horn_capture_cover.stl | PLA+PETG | measure the delivered D85MG bag arm first (accepted: length 18-27, width 4.0 +0.6/-0, thickness 1.8-2.6 — PROVISIONAL); seat it in the slot, clamp the cover (M3x8 + inserts, 3.2 stack), hold 2x rated stall torque on the slot flanks warm and cold, then 10 remove/refit cycles with no flank yield, cracking, or retention loss; tune the cover rib height to the measured thickness

Codex Rover Bean · Builder’s BookPage 12 of 45

PRINT

Chapter 2 · Print

## Print the little test parts first (2 of 2)

Print them from codex_robot_body_v2_proofs_p1s.3mf. These checks are specific to the exact PLA/PETG product lines you load. A pass never transfers to another brand, subtype, or effect filament.

Test part | Filament | What it proves
PLA insert boss proof_pla_insert_shell.stl | PLA | Use your exact body PLA and record the insert temperature. No white stress marks, cracks, sink, tilt, or pull-through.
PLA shell wall proof_pla_shell_wall.stl | PLA | Check the wall, rounded edge, opening, and panel seat after a bump test, warm soak, and full cool-down.
PLA snap proof_pla_snap_pair.stl | PLA | Print this in every candidate visible PLA. Click it ten times; it must still latch fully with no whitening or crack.
PLA light test proof_pla_optical.stl | Translucent PLA | Print once per translucent PLA family/color. Compare the three thicknesses for brightness, hot spots, heat, and camera flare.
PETG lid socket proof_lid_boundary_petg.stl | White PETG | Print with the white PETG lid profile and mate it to the teal PLA tab. The blind socket must not crack.
PLA skin tab proof_lid_boundary_pla.stl | Teal PLA | Snap into the white PETG proof ten times, warm it, and check that it still holds without rattling.

RECORD BEFORE PASS: manufacturer · product line · subtype · color · nozzle · layer height · wall count · insert-tool temperature (when used) · measurements · pass/fail · tester · date. Blank evidence means the gate is open.

Codex Rover Bean · Builder’s BookPage 13 of 45

PRINT

Chapter 2 · Print

## Proof qualification record — blank means OPEN

Printer / serial: ____________________

Nozzle: ______

Date started: __________

Test | Required family | Exact product + color | Settings + measurements | Result | Tester | Date
Insert fit | PETG | | | □ P □ F
Screw joint | PETG | | | □ P □ F
Screw joint partner | PETG | | | □ P □ F
Wheel grip | PETG | | | □ P □ F
Axle spin | PETG | | | □ P □ F
Axle spin ring | PETG | | | □ P □ F
Snap click | PETG | | | □ P □ F
Bayonet twist | PETG | | | □ P □ F
Switch pocket | PETG | | | □ P □ F
Tire stretch | TPU+PETG | | | □ P □ F
Board clamp | PETG | | | □ P □ F
PLA insert boss | PLA | | | □ P □ F
PLA shell wall | PLA | | | □ P □ F
proof_horn_capture | PLA+PETG | | | □ P □ F
PLA snap | PLA | | | □ P □ F
PLA light test | Translucent PLA | | | □ P □ F
PETG lid socket | White PETG | | | □ P □ F
PLA skin tab | Teal PLA | | | □ P □ F

Attach detail sheets for loads, cycles, temperatures, photos, and failure notes. Every row must identify the exact machine, spool product/color, settings, measured result, tester, and date; another spool family’s pass does not transfer.

Codex Rover Bean · Builder’s BookPage 14 of 45

PRINT

Chapter 2 · Print

## When the printer stops: count your pieces

All 45 printed pieces: 40 installed functional parts, 4 spare washers, and 1 optional cosmetic skin. Line yours up before Chapter 3; the dot shows each piece’s current effective color.

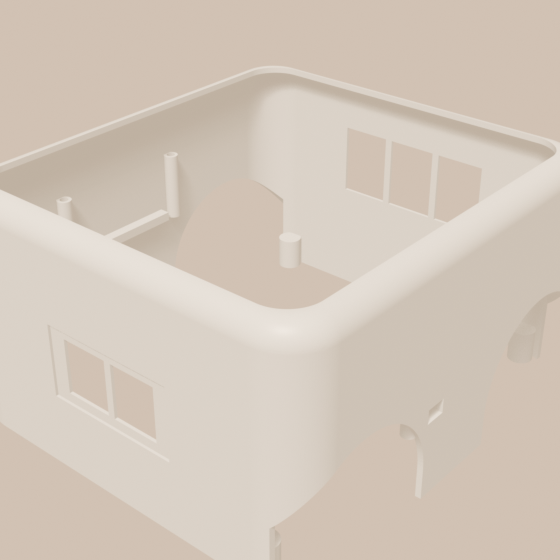
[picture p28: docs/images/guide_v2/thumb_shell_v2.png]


body shell

×1

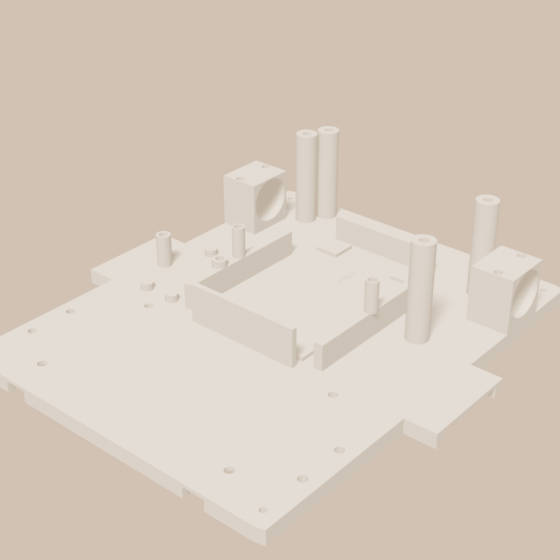
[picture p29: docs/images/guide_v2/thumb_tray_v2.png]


floor tray

×1

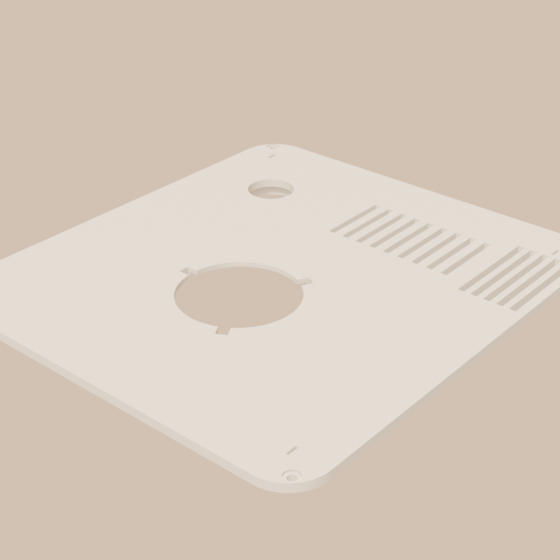
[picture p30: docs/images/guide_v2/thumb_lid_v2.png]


lid

×1

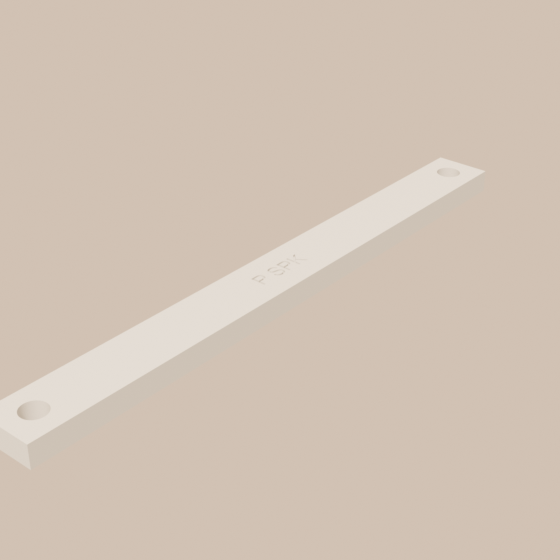
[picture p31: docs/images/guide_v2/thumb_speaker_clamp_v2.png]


speaker clamp

×2

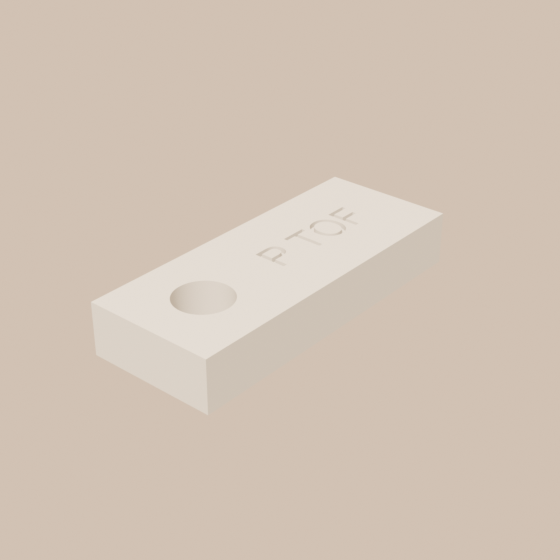
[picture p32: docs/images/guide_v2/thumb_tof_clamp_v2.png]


sensor clamp

×2

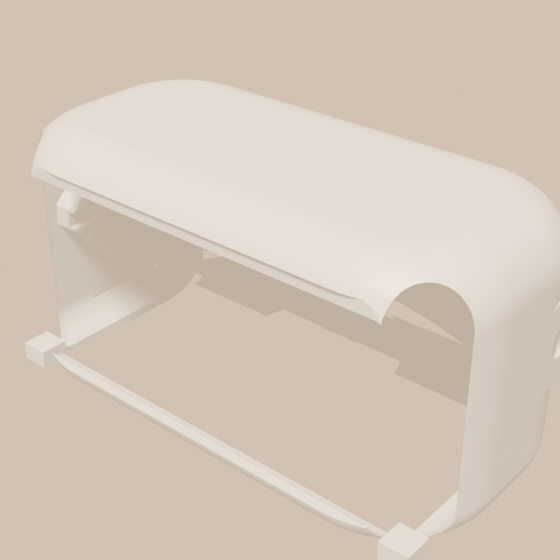
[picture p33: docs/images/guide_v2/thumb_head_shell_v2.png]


head shell

×1

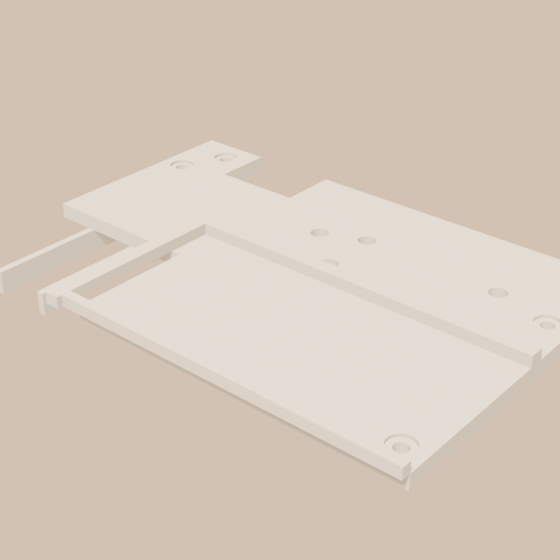
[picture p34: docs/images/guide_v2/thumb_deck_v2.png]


power deck

×1



brain tower

×1

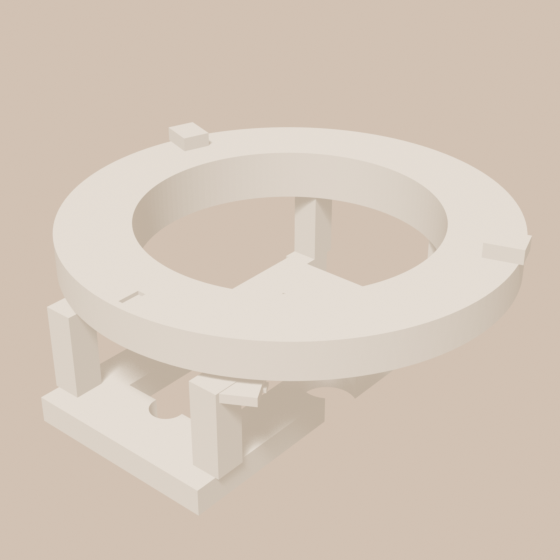
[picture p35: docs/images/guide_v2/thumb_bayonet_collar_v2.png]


neck collar

×1

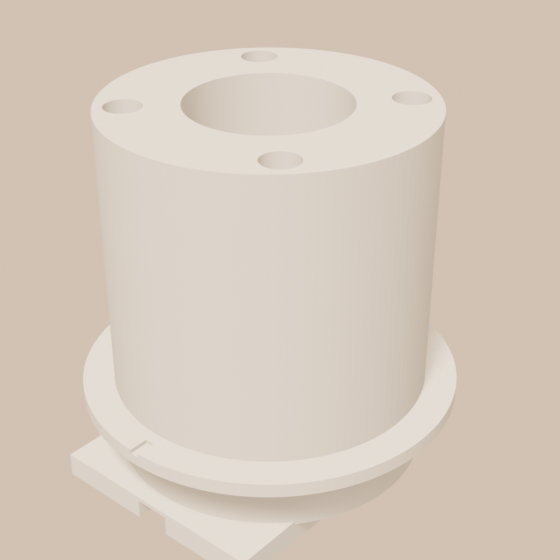
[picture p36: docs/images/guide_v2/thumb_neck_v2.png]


neck

×1

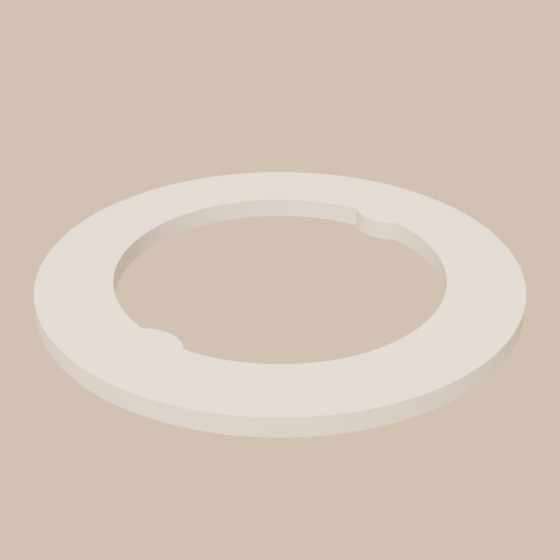
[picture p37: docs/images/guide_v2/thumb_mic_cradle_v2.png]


mic cradle

×1

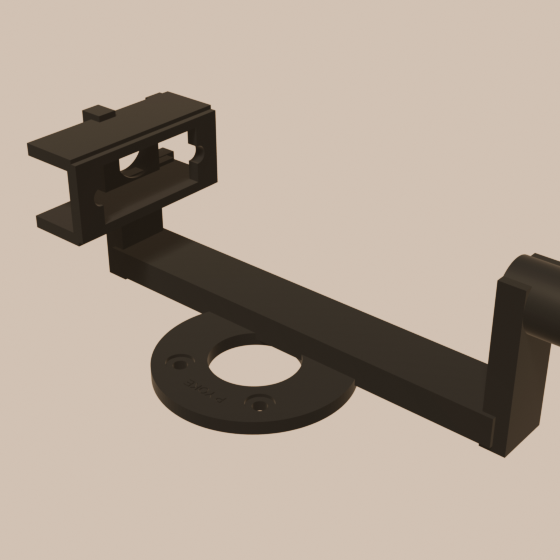
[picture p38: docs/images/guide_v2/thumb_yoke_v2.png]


head yoke

×1

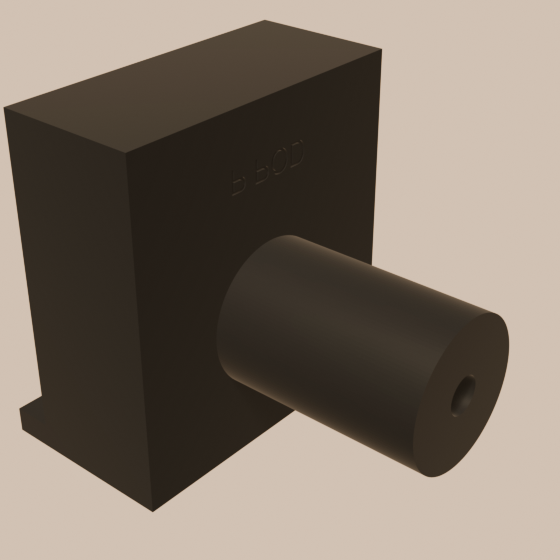
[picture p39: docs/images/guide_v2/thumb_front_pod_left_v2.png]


front pod (L)

×1

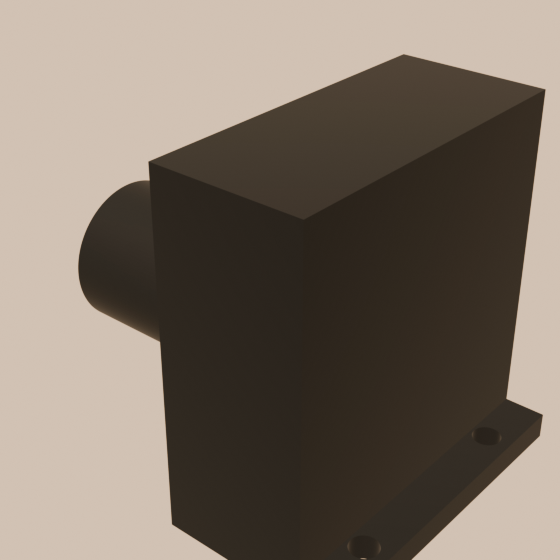
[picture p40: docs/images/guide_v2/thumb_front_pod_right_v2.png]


front pod (R)

×1

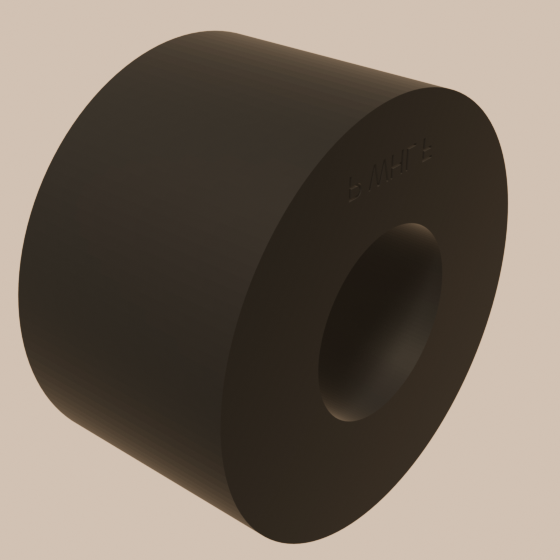
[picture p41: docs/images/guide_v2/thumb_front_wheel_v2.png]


front wheel

×2

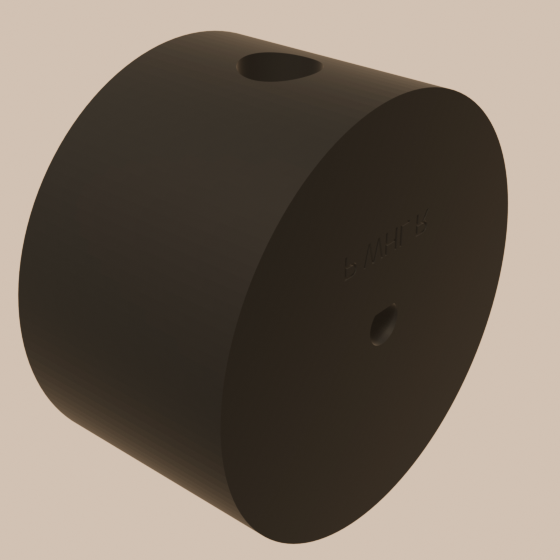
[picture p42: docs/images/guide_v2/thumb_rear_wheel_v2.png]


back wheel

×2

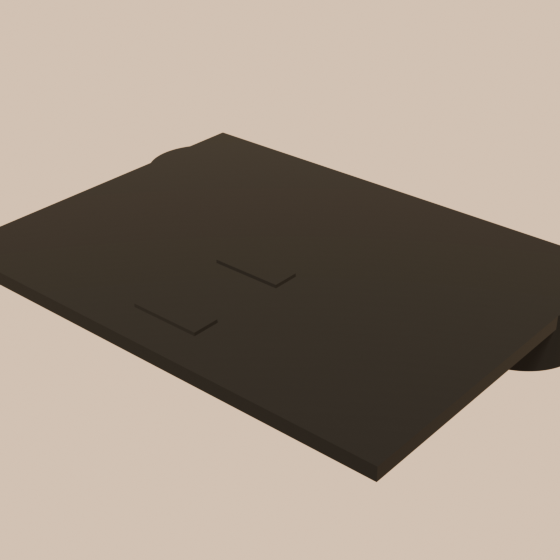
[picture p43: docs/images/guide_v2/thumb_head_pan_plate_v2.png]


pan slot cover

×1

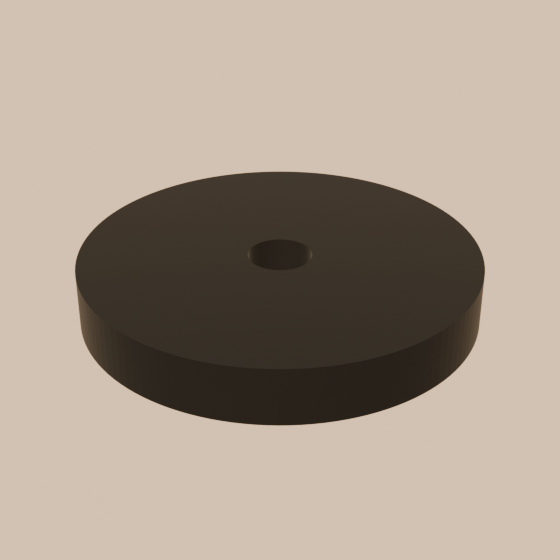
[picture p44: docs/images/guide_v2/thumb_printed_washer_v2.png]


washer

×6 (4 spares)



tilt bushing

×1



battery clamp

×1



safety-board clamp

×1



motor cap

×2



head face

×1



back panel

×1



face panel

×1



optional lid skin

×1



eye light bar

×1



status light bar

×1



front bumper

×1



back bumper

×1



battery pad

×1



tire

×4

Codex Rover Bean · Builder’s BookPage 15 of 45

BUILD



Chapter 3 · Build

# Build it

Twenty steps. Lay out the parts from each step’s GATHER strip before you start, match the big picture, then run the green CHECK.

The little FRONT tag on the robot pictures points at the robot’s face, so left and right never get confusing. (The wheel-bench step has no robot in it — no tag.) Magenta arrows slide floating parts into their landing rings.

One rule: go in order. The steps nest — skipping ahead means taking things apart later.

1Start with the floor

2Melt in the tray’s brass inserts

3Drop in the motors

4Make the wheels

5Bolt on the front pods

6Put the wheels on

7Build the brain tower

8Add the computer

9Dry-fit the battery, then remove it

10Add the safety helper

11Mount the power relay

12Put on the power deck

13Lower the body shell

14Feeler switches, then bumpers

15Face and back panels (with the front eyes)

16Speakers and distance eyes

17The lid and the BIG RED BUTTON

18Build the pan journal and neck

19Build the tilt head and camera

20Give it a face

BUILD

1

## Start with the floor

STEP 1 OF 20

GATHER



×1floor tray



↙ FRONT

1. Clear a big table. Put the tray down flat, wheel cutouts toward you.
2. Find the two round motor cradles at the back and the tall round towers — that’s the back of the robot.

CHECKThe tray sits flat and doesn’t rock.

Codex Rover Bean · Builder’s BookPage 17 of 45

BUILD

2

## Melt in the tray’s brass inserts

STEP 2 OF 20

GATHER



×20brass inserts



↙ FRONT

1. Heat the soldering iron to about 220 °C — insert temperature.
2. Rest a brass insert in each gold-marked hole, then press it straight down with the hot iron tip until it sits flush. (The gold pegs in the pictures just point at the holes — the real insert always ends up flush inside, nothing sticking out.)
3. 20 go into the tray now — the picture marks every spot. The other 31 come later: 2 in the wheels, 2 in the front pods, 4 in the power deck, 14 in the shell, 2 in the lid, 6 in the neck, and 1 in the head. The book calls for each batch when it’s time.

CHECKEvery insert is flush and straight, none tilted.

Codex Rover Bean · Builder’s BookPage 18 of 45

BUILD

3

## Drop in the motors

STEP 3 OF 20

GATHER



×2gearmotors



×2motor caps



×4M3 screws



↖ FRONT (far side)

1. Lay a motor in each cradle with the metal shaft poking OUT through the hole toward the wheel side.
2. Point each motor’s wire end — the end without the shaft — inward, toward the middle of the robot. (The picture’s plain grey motors leave the wires off.)
3. Set a printed cap over each motor and screw it down with 2 screws per cap — snug, not gorilla-tight.

CHECKMotors don’t wiggle. Each shaft turns when you twist it firmly — the gearbox drags, and that’s normal.

Codex Rover Bean · Builder’s BookPage 19 of 45

BUILD

4

## Make the wheels

STEP 4 OF 20

GATHER



×2back wheel



×2front wheel



×4tire



×2brass inserts



Rear wheel cutaway: port, deep insert, screw, shaft

1. The picture’s tags say which two are the BACK wheels (small middle hole with a flat). Each BACK wheel has a little screw well — a small round hole in its rim, shown in the cutaway. Drop 1 insert down each well (2 total), then press it to the bottom with the tip of the iron. It seats deep inside the wheel, close to the axle — nothing pokes out.
2. Stretch a stretchy printed tire over each of the four wheels, like putting a rubber band on a yo-yo.
3. Every tire has one little round port in its tread. On the BACK wheels, spin the tire until the port sits right over the screw well — poke a hex key through the port; it should slide into the well (the front wheels don’t care).
4. Work each tire around evenly until it sits flat in the groove all the way around.

CHECKNo tire bulges, and a hex key through each BACK tire’s port drops into the screw well.

Codex Rover Bean · Builder’s BookPage 20 of 45

BUILD

5

## Bolt on the front pods

STEP 5 OF 20

GATHER



×2front pods



×2brass inserts



×4M3 screws



↙ FRONT

1. Melt 1 insert into the end of each pod’s peg (2 total).
2. The two front pods have round pegs sticking out — those pegs are the front axles.
3. Screw each pod to the tray through its little foot tabs, 2 screws each, pegs pointing OUT.

CHECKBoth pegs point straight out to the sides.

Codex Rover Bean · Builder’s BookPage 21 of 45

BUILD

6

## Put the wheels on

STEP 6 OF 20

GATHER



×2back wheel



×2front wheel



×2washer



×4M3 screws



↖ FRONT (far side)

Detail A - rear wheel clamp path

Detail B - front cap washer overlap

1. BACK wheels: the hole has a flat side, and so does the motor shaft. Line the flats up, push the wheel on, then drop the clamp screw down through the tire’s port and tighten until it presses snug on the shaft’s flat.
2. FRONT wheels: slide onto the pegs — they should spin freely. Put a printed cap washer over the end (it covers the wheel’s middle hole), then a screw into the peg to keep the wheel from sliding off.
3. Don’t overtighten the front screws: the wheels must still spin.
4. You printed extra washers — drop the leftovers in your spares box.

CHECKBack wheels should NOT spin freely by hand (the motor holds them). Front wheels spin freely.

Codex Rover Bean · Builder’s BookPage 22 of 45

BUILD

7

## Build the brain tower

STEP 7 OF 20

GATHER



×1brain tower



×1motor board



×4M3 screws



↙ FRONT

R←FRONT · IT FACES YOU→L

1. Set the tower over the front of the tray — its screw holes match the four inserts.
2. Drive 4 screws down through the base tabs.
3. Rest the purple motor board on the four little posts, its green terminal blocks facing the RIGHT side of the robot.

CHECKThe board sits level on all four posts, terminals facing right.

Codex Rover Bean · Builder’s BookPage 23 of 45

BUILD

8

## Add the computer

STEP 8 OF 20

GATHER



×1Raspberry Pi



↙ FRONT

1. The Raspberry Pi lies flat on the tower’s top shelf frame.
2. Its USB ports face the BACK of the robot so the cables can reach.
3. Don’t screw anything — the shelf pocket holds it, and the head’s camera cable drops down to it in step 19.

CHECKThe Pi sits in its pocket, ports facing backward.

Codex Rover Bean · Builder’s BookPage 24 of 45

BUILD

9

## Dry-fit the battery, then remove it

STEP 9 OF 20

GATHER



×1battery pad



×1battery



×1battery clamp



×2M3 screws



↙ FRONT

1. Lay the soft TPU pad frame onto the four little floor pads behind the tower — the arrow shows the bay; the pads hide behind the tower from this angle.
2. Set the battery on it, wires pointing at the BACK of the robot.
3. Bridge the clamp bar across the battery onto the two posts and screw it down with 2 screws — firm, so the battery cannot slide.
4. This is a DRY FIT only. Remove the screws, clamp, battery, and soft pad; put the battery in a safe box away from the build until the meter-check page calls for it.

CHECKThe battery fits without wrapper pinch or lead strain, and is now outside the robot.

Codex Rover Bean · Builder’s BookPage 25 of 45

BUILD

10

## Add the safety helper

STEP 10 OF 20

GATHER



×1Pico 2



×1safety-board clamp



×2M3 screws



↙ FRONT



USB toward BACK; SWD toward FRONT; clamp touches blank PCB edges only

1. The tiny green Pico sits on its little posts to the right of the tower, USB service end facing the BACK of the robot.
2. USB and SWD are service-only. Never cable either one to the Pi inside the robot.
3. Lay the small clamp bar across it and screw it down with 2 screws, gently — it’s a small board.

CHECKThe Pico is held snug, its USB end points back, and no USB/SWD cable is installed.

Codex Rover Bean · Builder’s BookPage 26 of 45

BUILD

11

## Mount the power relay

STEP 11 OF 20

GATHER



×1relay



↙ FRONT

R←FRONT · IT FACES YOU→L

1. The relay drops into its floor pocket on the left, behind the tower.
2. Its metal bracket slots into the printed pocket; the terminals face UP so they’re easy to wire later.
3. No wires yet — the wiring chapter at the back of this book is the reference map for the future harness release.

CHECKThe relay clicks into its pocket and doesn’t rattle.

Codex Rover Bean · Builder’s BookPage 27 of 45

BUILD

12

## Put on the power deck

STEP 12 OF 20

GATHER



×1power deck



×1fuse block



×2regulators



×4brass inserts



×8M3 screws



↙ FRONT

R←FRONT · IT FACES YOU→L



Detail A - underside: distinct 5 V and 6 V regulators



Detail B - topside: covered fuse block and LEFT wire edge

1. Flip the deck over and melt 4 inserts into the regulator stations (the jig keeps them straight), then seat the green 5 V regulator board in its underside bay and snug its 2 screws — the screw heads hold the board’s edges like little hands. Since D053 this one board feeds the computer AND the head; the second bay stays empty on purpose (a reserved spare in case the shared-rail test ever demands a separate 6 V board).
2. Lower the deck onto the four towers — the notch at the back-right corner is where the battery’s wires will pass once it moves back in.
3. Drive 4 screws down into the tower tops.
4. Set the black fuse box into its raised outline on the deck’s LEFT half, wire tail hanging over the left edge.

CHECKThe deck is level and the fuse box sits inside its printed fence.

Codex Rover Bean · Builder’s BookPage 28 of 45

BUILD

13

## Lower the body shell

STEP 13 OF 20

GATHER



×1body shell



×14brass inserts



×4M3 screws



↙ FRONT



All 14 insert spots

1. Melt the shell’s 14 inserts first (4 corner lugs, 4 lid-ledge holes, 4 speaker posts, 2 sensor bosses).
2. Two people make this easy: lower the big shell straight down over EVERYTHING.
3. The wheel arches go around the wheels; the lip settles onto the tray edge.
4. Flip-check the underside: drive 4 screws UP through the tray’s corner holes into the shell’s lugs.

CHECKNo gaps between shell and tray. The robot is now a box with wheels.

Codex Rover Bean · Builder’s BookPage 29 of 45

BUILD

14

## Feeler switches, then bumpers

STEP 14 OF 20

GATHER



×6feeler switches



×2bumpers



↙ FRONT



Detail A - 6 switches: buttons OUT, leads IN

Detail B - side section: rest, click, hard stop

1. Tip the robot gently onto its side. Click each of the six little feeler switches into its pocket under the tray edge — two front, two back, one each side. Their tiny buttons face OUT.
2. Their wires tuck up inside for the wiring chapter.
3. Stand the robot back up. The two soft bumper halves wrap around the bottom, one from the front, one from the back.
4. They hug the body loosely on purpose — they squish in to press those feeler switches.

CHECKPress any bumper edge gently: it moves a tiny bit, you hear a soft click, and it springs back.

Codex Rover Bean · Builder’s BookPage 30 of 45

BUILD

15

## Face and back panels (with the front eyes)

STEP 15 OF 20

GATHER



×1face panel



×2distance boards



×1back panel



↙ FRONT



Detail B - rear: charge LEFT, blank center, mute RIGHT

Detail A - back of fascia: sensors and status lights

1. First press the two front distance boards into the pockets on the FACE panel’s back — their little lenses peer through the two low holes.
2. Click the FACE panel into the front opening.
3. The dark BACK panel clicks into the back opening. Its two round holes are for the charger plug and the mute switch — their own nuts hold them once the harness release closes; in this dry build the holes stay empty.
4. The face panel’s two light slots stay see-through into the body until the lime bars clip in at step 20 — that’s normal.

CHECKBoth panels sit flush; two tiny lenses look out of the face.

Codex Rover Bean · Builder’s BookPage 31 of 45

BUILD

16

## Speakers and distance eyes

STEP 16 OF 20

GATHER



×2speakers



×2distance boards



×2speaker clamp



×2sensor clamp



×6M3 screws



↙ FRONT



Detail A - speaker: grille OUT, magnet IN; clamp + ToF

Detail B - one-side orientation and wire exit

1. Reach in through the open top: rest a speaker on each side shelf, magnet side in, grille facing the wall.
2. Lay a clamp bar across each speaker’s top and screw into the two posts (2 screws per side) — the inserts went in with the shell step.
3. OPTIONAL: the side distance boards are garnish, not safety (D057) — the bumpers feel and the camera sees. If you bought the extra pair, slide one behind each side window, then its clamp bar and 1 screw; if not, install the empty clamp bars the same way and the windows just look cool.

CHECKSpeakers can’t rattle; the clamp bars are snug (with or without side boards behind the windows).

Codex Rover Bean · Builder’s BookPage 32 of 45

BUILD

17

## The lid and the BIG RED BUTTON

STEP 17 OF 20

GATHER



×1lid



×1optional lid skin



×1red button



×1mic array



×1mic cradle



×2brass inserts



×2M3 screws



↙ FRONT



Detail A - lid flipped: the 2 mic bosses



Detail B - full E-stop body, nut, and 2 NC blocks

Detail C - E-stop lid load path and terminal corridor

1. Melt the lid’s 2 mic-boss inserts, then drop the red emergency-stop through the SMALLER of the lid’s two round holes (the big front one belongs to the neck) and spin its nut on underneath — the lid IS its mounting panel, and the printed ring under the lid makes it strong.
2. Set the round microphone under the lid’s slotted area and screw its ring cradle to the two bosses (2 screws).
3. OPTIONAL: after the E-stop is clamped, press the teal skin’s four integral tabs into the lid’s blind pockets. It stays above the lid and never goes under the E-stop nut, neck, microphone, or corner screws.
4. Rest the lid in its ledge — DON’T screw it yet. The neck, the head, and all the wiring still need the inside. Its 4 corner screws are the very last thing in this book.

CHECKThe optional skin sits flat with every slot open; with the PETG lid supported and nut tight, a centered firm press latches the red button; twist to release.

Codex Rover Bean · Builder’s BookPage 33 of 45

BUILD

18

## Build the pan journal and neck

STEP 18 OF 20

GATHER



×1neck



×1neck collar



×1pan slot cover



×1D85MG servo (arm in its bag)



×6brass inserts



×2M3 screws



↙ FRONT



Lid hidden: collar, cradle, servo, slot cover, bag arm

DELIVERED-ARM PROOF FIRST — the arm from your servo's bag must pass the horn-capture proof (chapter 2) before it goes in; the capture slot's sizes are provisional until real arms are measured.

1. Melt 4 inserts into the neck’s top flange and 2 into its underside capture-pad bores — the insert jigs from the tools plate hold them square. Keep heat away from the smooth journal and thrust faces.
2. From above the loose lid, align the collar’s 3 lugs with the keyways, press through, and twist about 20° until all 3 detents sit in the blind underside race.
3. Flip the supported lid. Set the pan D85MG into the cradle with its shaft UP and bolt its mounting ears to the two frame stations with the screws and nuts from the servo’s own bag. The case must not be pinched.
4. Take the single arm out of the servo’s own bag and land it on the spline tooth closest to the two tick marks lining up — the marks on the collar and neck show center, and the robot’s software trims away the last few degrees later. Fix it with the bag’s spline screw; never force the gears by hand.
5. Smear a thin film of grease (tools list) on the journal and thrust faces, feed the camera ribbon through the open +X crescent, lower the neck journal into the collar so the arm slides into the neck’s capture slot, and clamp the slot cover over it with 2 M3 screws — the slot walls carry the turning force, not the screws.

CHECKThe neck sits flat on the greased thrust face; it turns by hand through ±60°, meets both hard stops beyond that range, has no lift, and never rubs the ribbon.

Codex Rover Bean · Builder’s BookPage 34 of 45

BUILD

19

## Build the tilt head and camera

STEP 19 OF 20

GATHER



×1head shell



×1head yoke



×1camera



×1D85MG servo (arm in its bag)



×1tilt bushing



×1brass insert



×5M3 screws



↙ FRONT



Tilt servo, bag arm, hard stops, passive bushing



Camera board, lens, and ribbon entrance

DELIVERED-ARM PROOF FIRST — same hold as step 18; prove the bag arm in the capture proof before building the head.

1. Melt 1 insert into the yoke’s passive-pivot boss from the OUTSIDE end. Seat the yoke on the neck and install its 4 M3 screws without trapping the center ribbon.
2. Mount the second D85MG sideways in the active frame with the grommets, eyelets, screws, and nuts from its own bag. Land its bag arm on the spline tooth closest to the tick marks on the yoke and head boss — software trims the rest.
3. Slide the head shell over the yoke so the arm settles into the shell’s capture slot — the slot walls carry the turning force. The servo supplies torque; the printed pivots carry the head.
4. From the -Y outside face, slide the black shoulder bushing through the shell and install 1 M3 screw into the yoke insert. Tighten against the bushing’s 3.2 mm sleeve — never pinch the moving shell.
5. Dry-seat the Camera Module 3 behind the face opening and feed its FPC down the hollow neck. Permanent camera-board retention and the exact harness remain prototype release gates.

CHECKThe bushing flange is flush; the shell has no axial pinch, hand-tilts freely through ±20°, and contacts both printed hard stops only beyond the commanded range.

Codex Rover Bean · Builder’s BookPage 35 of 45

BUILD

20

## Give it a face

STEP 20 OF 20

GATHER



×1head face



×1eye light bar



×1status light bar



↙ FRONT

Detail - body status bar: diffuser, boards, plug direction

1. Clip the lime eye bar behind the HEAD face’s eye slots (glow boards ride behind it).
2. Press the head face into its recess on the head shell: camera hole over the lens.
3. The second lime bar clips behind the body face panel’s light slots — each glow board rides in the pocket behind its bar.
4. Leave the 4 glow boards in their bag for now — they seat in those pockets when the NeoPixel harness release closes.

CHECKRover Bean is looking at you. Say hi.

Codex Rover Bean · Builder’s BookPage 36 of 45

WIRE

Chapter 4 · Wire

## Where every electronic part lives



Part | Home | Faces
MDDS10 motor board | tower posts, front-center | terminals RIGHT
Raspberry Pi 5 | tower top shelf | USB ports BACK
Pico 2 | floor, right of tower | USB/SWD service ends accessible; never cabled to Pi
Battery | middle-back floor | wires BACK
Relay | floor pocket, left | terminals UP
Fuse block | deck, left half | wire exit LEFT edge
Regulator (5 V — computer + head) | hangs UNDER deck, back half; spare bay beside it | servo-branch wire exit FRONT
Big red button | through the lid | UP; test with a centered firm press
Mic array | under the lid slots | UP
Speakers | side shelves | grilles OUT
ToF distance boards | 2 behind face, 2 side windows | lenses OUT
Bumper feeler switches ×6 | pockets under the tray edge | buttons OUT
Charger inlet + mute | back panel holes | BACK
Camera | head, pocket behind the face opening | lens FRONT
Pan + tilt servos | pan inside the neck, tilt in the head’s side | pan shaft UP, tilt shaft SIDEWAYS
Glow boards ×4 | pockets behind the eye + status bars | lights OUT

The cutaway hides the shell, lid, and head, so parts that mount on them — the white neck collar ring, the side speakers — hover at their true installed heights.

PROTOTYPE HOLD: This populated cutaway proves placement only. MAX98357A mounts, NeoPixel installation, and the exact harness schedule are not released yet.

Codex Rover Bean · Builder’s BookPage 37 of 45

WIRE

Chapter 4 · Wire

## The wiring rules

This chapter is the REFERENCE MAP for a harness that is not released yet — no step in this book cuts a wire. Read it to understand the design; build it only when the wire/terminal/fuse releases close.

Wiring is the careful part. Read this whole chapter once, start to finish, before cutting a single wire.

The battery stays OUT of the robot until every wire is checked against these maps.

Use wire colors: RED = battery 12 V, YELLOW = switched motor 12 V, BLUE = 5 V computer, GREEN = 5 V head-servo branch, BLACK = ground, WHITE = signals.

Crimp or solder every joint; no bare twists. Label both ends of every wire with tape.

Fuse values are UNSET — NOT RELEASED. Do not install any from a prose guess; measured loads, conductor ampacity, inrush, time-current, selective-clearing, and thermal tests must close first.

The robot must FAIL STOPPED: if any of this feels wrong, it stays off.

### The power map (every 12 V wire)

From | Through | To
Battery +12 V | covered split → accessory feeder fuse | Blue Sea fuse block IN
Fuse branch 1 | D24V90F5 regulator | protected 5 V harness — computer AND head servos (D053); Pi input + shared-rail proof BLOCKED
Fuse branch 2 | covered spare (the 6 V rail retired to it, D053) | no assigned load or fuse value
Fuse branches 3 + 4 | covered spare positions | no assigned loads or fuse values
Battery +12 V | separate motor fuse → relay contacts | MDDS10 motor board power
12 V coil feed (exact tap OPEN) | BOTH E-stop NC contacts + driver (proof BLOCKED) | relay coil
Charger EN2 | assigned contacts TBD | charge pair + protected charger-present; BLOCKED

Codex Rover Bean · Builder’s BookPage 38 of 45

WIRE

Chapter 4 · Wire

## Power, as a picture

Codex Rover Bean · Builder’s BookPage 39 of 45

WIRE

Chapter 4 · Wire

## The signal map (thin wires)

PICO USB/SWD ARE SERVICE-ONLY. DO NOT CONNECT THEM TO THE PI INSIDE THE ROBOT.

From | To | What travels
Raspberry Pi / robotd | Pico 2 | framed UART commands + heartbeat; no flash or config-write path
Pico 2 | MDDS10 | clamped velocity outputs after leases, watchdog, and latch checks
Motor encoders (6 wires each) | Pico 2 | wheel speed feedback
Bumper switches ×6 | Pico 2 | any open NC loop = latched stop in independent safety firmware
ToF boards ×4 | Raspberry Pi | I2C + four XSHUT branches; connectors and address proof open
NeoPixels ×4 | Raspberry Pi | data line; level shift, resistor, capacitance, and harness open
Camera | Raspberry Pi | flat FPC ribbon down the hollow neck
Servos ×2 | Pico 2 | future clamped PWM after RBSP HEAD; pins/outputs/harness open
Mic array | Raspberry Pi | USB data; physical VBUS cut and no-backfeed circuit BLOCKED
Pi I2S pins | MAX98357A amps | digital sound out; board mounts, channel straps, terminals, and strain relief not released

### Cable neatness

Quiet wires (signals, audio, sensors) ride the LEFT channel under the deck. Power wires ride the RIGHT channel. The camera ribbon goes up the little tunnel beside the neck servo, through the hollow neck, into the head. Zip-tie at every printed tie point; no wire may touch a wheel or the fan.

### The meter checklist (preview — runs only after the harness release)

Nothing below happens today; it goes live with the released harness. First, no shorts: beep-test + to − at the fuse block (no fuses in yet). Then:

1. Red button held down = relay coil circuit reads OPEN.
2. The regulator output reads 5.0–5.2 V on the bench — under compute load AND a head-servo sweep — before anything else connects.
3. Do not choose or install fuses until the measured-load, conductor, inrush, selective-clearing, and thermal evidence is released.
4. Charger plug in = motors will not run.
5. The eventual first powered test (its own future release) starts with the lid closed with its 4 corner screws; reopen only while shut down with the motor branch physically isolated.

Codex Rover Bean · Builder’s BookPage 40 of 45

PLAY



Chapter 5 · Check & play

PROTOTYPE PREVIEW — NO POWERED MOTION

## The body preview is assembled

This version really ships the robot’s software: the Pi installer, the robotd body daemon with its supervision dashboard, the fixed Pi-to-Pico message rules, a tested safety core that always fails stopped, the wiring plan, and the step-by-step commissioning checklist. What it does not ship: production motor outputs, exact wire lengths and fuse values, or signed physical test results. Do not energize the motor branch from this book.

### Commissioning gate

A released checklist must cover both E-stop NC channels and physical reset; all six NC bumper zones plus a broken wire; watchdog and setpoint-lease expiry; velocity/acceleration clamps; charger inhibit; low-battery cutoff; hardware mic mute with no backfeed; regulator polarity and voltage; branch-by-branch power-up; stop latency; motor direction; and a wheels-off-ground run before any floor test.

Until those physical results and production integrations exist, the body’s number one rule is wonderfully easy: admire, measure, and keep the battery out.

The brain is a different story. Nothing on the next three pages needs the battery, the motors, or a single open gate — you can wake Rover Bean’s mind up tonight.

PLAY

Chapter 5 · Check & play

## Wake the brain up tonight (no robot needed)

The robot’s mind ships in this release as two programs: robotd, the body daemon, and a supervision dashboard. They run on any Mac or Linux computer with Python 3.11 or newer — today, before a single part is printed — because robotd carries a deterministic pretend body (the simulator) for exactly this.

Open a terminal in the downloaded release folder and type:

python3 -m venv /tmp/rover-bean /tmp/rover-bean/bin/pip install -e software/robotd \ -e software/dashboard /tmp/rover-bean/bin/robotd --simulate --socket /tmp/robotd.sock \ --blackbox /tmp/robotd-blackbox.jsonl & /tmp/rover-bean/bin/robot-dashboard --socket /tmp/robotd.sock \ --blackbox /tmp/robotd-blackbox.jsonl

Then point a browser at http://127.0.0.1:8072/ — the page in this picture, live on your desk. It only ever listens to your own computer. When you want the pretend body to perform, run /tmp/rover-bean/bin/robot-hello --socket /tmp/robotd.sock — Rover Bean looks left, looks right, and settles back to center, narrating as it goes. On the real robot this same script is the mid-build wake-up: head and lights only, battery still out, no gate crossed.

It’s a window, not a remote override. The dashboard talks to robotd like every other client. On the real robot the Pico firmware still owns safety: it cannot clear an E-stop latch, cannot bypass the open-bumper zero-motion rule, and cannot exceed the firmware speed clamps. Release a drive button (or lose the page) and the firmware’s 250 ms lease zeros motion by itself.

CHECK The STATUS card reads robotd reachable · firmware link up, and dragging the head slider changes its numbers while the blackbox log grows.



1STATUS — the simulated body reporting in: battery, speed, and the head aimed at pan 25.0°, tilt −8.0° from the little session below.

2SAFETY FLAGS + BUMPER LOOPS — quiet chips mean nothing is latched. Six NC zones; any open loop means zero motion (D036), and this page can show that but never overrule it.

3DRIVE + HEAD — hold-to-drive buttons and sliders, capped at the firmware limits the page prints next to each control.

4BLACKBOX LOG — the flight recorder. Every command from every client lands here with its source name. This capture shows a source="agent" session: a head aim, one drive setpoint, a stop.

Codex Rover Bean · Builder’s BookPage 42 of 45

PLAY

Chapter 5 · Check & play

## Move the brain into the robot

The robot’s real computer is the Raspberry Pi 5 from your electronics box. The release turns a fresh Pi into the versioned bench appliance — same robotd, plus key-only SSH through an outbound-only Cloudflare Tunnel (the robot opens no door into your house), recorded shell sessions, and a stable name for the safety Pico’s wire. This is the longest recipe in the book; the full card is docs/pi-appliance-provisioning.md in the release. The short version:

1. Flash the microSD with 64-bit Raspberry Pi OS Lite (Bookworm) using Raspberry Pi Imager, and boot the Pi once.
2. Make the robot’s only door. In Cloudflare Zero Trust (the free tier is fine): create a named Tunnel whose one route points your chosen hostname at ssh://localhost:22, protect that hostname with an Access application, and install cloudflared on the computer you will connect from.
3. Prepare three secret files outside the release folder, and never share or commit them: an option-free Ed25519 public key, a yescrypt console-password hash, and the Tunnel’s run token (one line each).
4. Run the installer on the Pi from the release folder:

sudo software/install.sh \ --ssh-public-key-file /secure/path/agent.pub \ --tunnel-token-file /secure/path/tunnel.token \ --console-password-hash-file /secure/path/console.hash \ --access-ready

5. Keep that first session open. From your second computer, SSH in through the tunnel, run the two attestation commands from the recipe card, and only then close the original session.
6. Reboot once and prove the two serial ports exactly as the card shows: the debug console still answers, and the Pico’s future wire is pinned to /dev/rover-pico — with the Pico’s USB and SWD still unplugged. They are service corridors, never robot wiring.

### What the installer refuses to do (on purpose)

It does not start robotd. On a first install the body daemon is parked — stopped and disabled — until the commissioning plan says otherwise.

It does not touch the Pico, the motor branch, or any power wiring. Software cannot close a physical gate.

It does not reboot for you, and it never prints your secrets.

### When the verifier stays red

The live check (appliance.py verify --live) stays red until the SSH, console, and independent audit-collector attestations all exist. Red here is the system telling the truth about missing evidence — not a sad robot. The 27-step commissioning plan in the release closes it.

CHECK A fresh SSH login works through the tunnel, both serial-port readbacks match the card, and systemctl status robotd reports it parked (inactive, disabled) — exactly as shipped.

Codex Rover Bean · Builder’s BookPage 43 of 45

PLAY

Chapter 5 · Check & play

## The copilot takes the seat

Rover Bean’s resident narrator is a frontier AI copilot — Claude or Codex, one at a time — living on the robot’s own computer. Through the tunnel you built on the last page, it gets the whole seat by design: it can log in from anywhere, read its own sensors, write and run new code for itself, install what it needs, and send drive and head setpoints to robotd like any other client. Root on the Pi is the copilot’s to hold.
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

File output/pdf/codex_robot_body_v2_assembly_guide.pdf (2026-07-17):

# CODEX ROVER BEAN

AGES 10+; 44 PIECES TO PRINT; 11 PLATES; 1 HEX KEY; GROWN-UP NEEDED: SOLDERING & WIRING; CODEX ROVER BEAN - Builder's Book; page 1 / 34

The Robot Body Builder's Book

Print it. Screw it together. Meet your robot.
Everything you need is in this book and one Bambu Studio file.

Chapters: 1 Shop - 2 Print - 3 Build - 4 Wire (grown-up) - 5 Check & play

# How this book works

## The pictures do the talking

Every build step shows the robot so far. On most pictures the NEW parts float just off their spot (early steps show them already home). The little dark tag with the arrow points toward the robot's FACE. Match the picture, then read the numbered lines if you want words too.

## The parts strip

The tan strip at the top of each step shows exactly which parts and how many screws you need before you start. Lay them out like a cooking show.

## The green CHECK bar

Do the little test at the bottom of each step before moving on. If the check fails, fix it now - later steps cover things up.

## Red circles mean grown-up

Steps with a red number use the soldering iron or touch wires. A grown-up does those; you can watch and help.
One screw. One key.

Every screw in this robot is the same M3 x 8 screw, and one 2.5 mm hex key turns them all. "Snug" means: stop when it stops, then an eighth of a turn. Plastic hates gorillas.

## Front and back

The FRONT is where the face panel and head look. The BACK has the charging plug, the mute switch, and the motor wheels. Left and right are the robot's left and right, not yours.

# Chapter 1 - Go shopping: plastic, screws, tools

## Filament (for the printer)

Filament | How much | What it becomes
Cream PETG | 1x 1 kg spool (uses ~600 g) | The body, tray, head, and most parts.
Teal PETG | 1x small spool or 250 g (uses ~80 g) | The top lid.
Charcoal / black PETG | leftovers are fine (~20 g) | Face panel, back panel, head face.
Translucent lime PETG | smallest spool available (uses ~5 g) | The glowing eye and light bars.
Charcoal TPU 95A | 1x 500 g spool (uses ~280 g) | Soft tires, bumpers, battery pad.

## The only two fastener packs

Fastener | Buy | Why
M3 x 8 mm socket head screws | 1x 100-pack | The ONLY screw in the robot (41 used + spares).

M3 x 5.7 mm brass heat-set
inserts (4.6 mm OD)

1x 100-
pack

The only insert (41 used + spares).

## Tools

Tool | Job
2.5 mm hex key | Turns every screw in this robot. Seriously, all of them.
Soldering iron (grown-up) | Melts the brass inserts into the plastic.
Small flush cutters / scissors | Trims zip ties and TPU strings.
Painter's tape + marker | Label wires as you go.
Multimeter (grown-up) | Checks every circuit before the battery ever goes in.

This screw and this brass
insert are the only fasteners you'll buy for the whole
robot. When a step says "2 screws," it always means
these.

# Chapter 1 - Go shopping: the electronics box (1 of 2)

Every item is a normal buy-one online part in the US. A grown-up orders these. Fuse sizes and wire gauges are right here in the list; the wiring chapter shows where each goes.

Part | Qty | What it does
Raspberry Pi 5 (8 GB) | 1 | The robot's computer.
32 GB+ A2 microSD card | 1 | The computer's memory card - the robot's programs live here.
Raspberry Pi Camera Module 3 Wide + long FPC cable | 1 | The robot's eye.
Raspberry Pi Pico 2 (no headers, no WiFi) | 1 | The safety helper: reflexes and watchdog.
Cytron MDDS10 motor driver | 1 | The purple board that powers the wheels.
Pololu #4867 gearmotor (99:1, 25D, 12 V, encoder) | 2 | The wheel motors.
Hitec D85MG servo | 2 | The neck motors (look left/right, up/down).
Bioenno BLF-1203AB 12 V 3 Ah LiFePO4 battery | 1 | The robot's power pack.
Bioenno BPC-1502DC charger | 1 | The matching charger. Only ever use this one.
Switchcraft EN2P3M20 inlet + EN2C3F20G2 plug | 1 pair | The keyed charging plug on the back.
Pololu D24V90F5 regulator (5 V) | 1 | Makes clean 5 V for the Pi.
Pololu D36V50F6 regulator (6 V) | 1 | Makes 6 V for the neck servos.

# Chapter 1 - Go shopping: the electronics box (2 of 2)

The rest of the electronics box:

Part | Qty | What it does
Panasonic CB1A-R-M-12V relay | 1 | The motor power switch the red button controls.
Blue Sea Systems 5045 fuse block | 1 | Splits power safely into four fused branches.
ATO fuses: 2 A, 3 A, 5 A, 7.5 A assortment | 1 kit | Branches start at 2-3 A (5 A max); feeder 7.5 A; motor branch 5 A. Grown- up confirms with the meter.
IDEC XW1E-BV402M-R emergency stop | 1 | THE BIG RED BUTTON.
E-Switch PVB3F230SS311 mute switch | 1 | The microphone privacy switch (glows red when muted).
Omron D2HW-C202MR bumper switches | 6 | Feelers inside the bumpers.
VL53L1X time-of-flight boards (Adafruit 3967) | 4 | Distance eyes: two in front, one each side.
Adafruit 5975 NeoPixel breakouts + JST-SH cables | 4 | The glowing eyes and status lights.
ReSpeaker USB mic array | 1 | The robot's ears.
Enclosed 3 W 4 ohm speakers + 2x Adafruit MAX98357A amps | 1 set | The robot's voice.
18 AWG (power) + 22 AWG (signal) silicone wire, JST/spade connectors, ferrules, zip ties, heat-shrink | 1 kit | Grown-up wiring supplies.

# Chapter 2 - Print it with Bambu Studio

## Open the project

Open codex_robot_body_v2_p1s.3mf in Bambu Studio. All 11 plates are already laid out for the P1S with a 0.4 mm nozzle and Textured PEI plate.

## Load the right color

Each plate's name says the filament to load (cream, teal, charcoal, lime, or TPU). Print plates one at a time and change filament between groups.
No supports. Ever.

Every part is designed to print with zero supports. If the slicer asks for supports, something is wrong - don't add them, re-check the plate.

## TPU is slow and squishy

Print the tire and bumper plates slowly (the profile already does this). Dry TPU prints much better.

## Big flat parts stay put

The tray, shell, and bumper plates fill the whole bed. Clean the plate with dish


soap first so they stick. | All 11 plates, exactly as they open in Bambu Studio.

# Chapter 2 - The 11 plates, in printing order

Plate (load this filament); Parts; What's on it; 1 Cream PETG -; Structural 1 of 3; tray; 2 Cream PETG - Structural 2 of 3

22 | deck, controller tower, battery clamp, speaker clamp #1, speaker clamp #2, yoke, mic cradle, head pan plate, pico clamp, front pod left, front pod right, motor cap #1, motor cap #2, tof clamp #1, tof clamp #2, tilt bushing, printed washer #1, printed washer #2, printed washer #3, printed washer #4, printed washer #5, printed washer #6 (the robot uses 2 washers - the rest are spares)

3 Cream PETG - Structural 3 of 3; 4 Cream PETG - Shell 1 of 2; shell; 5 Cream PETG - Shell 2 of 2; head shell, bayonet collar, neck; 6 Teal PETG - Shell; lid; 7 Charcoal PETG - Detail; 8 Translucent Lime PETG - Diffuser; status diffuser bar, eye diffuser bar; 9 Charcoal TPU; bumper front

4 | front wheel #1, front wheel #2, rear wheel #1, rear wheel #2
3 | head faceplate, rear panel, face panel

95A - Flexible 1 of 3; 10 Charcoal TPU 95A - Flexible 2 of 3; bumper rear; 11 Charcoal TPU

5 | battery pad frame, tire #1, tire #2, tire #3, tire #4

Tip: print plates 1-5 (cream) back to back, then change color once per group. Keep every part in a labeled box - the next chapter uses them in order.

# Chapter 2 - Print the little test parts FIRST

Before the big plates, ask your grown-up to print the little TEST PARTS that come with the project (the coupons folder next to the Bambu file). They make sure your printer's holes, snaps, and fits are dialed in - like tasting the batter before baking the whole cake. Each one has a simple pass test:

Test part | Filament | What it proves
insert m3 | PETG | Grown-up melts one insert into each of the three holes. The one that sits flush without squeezing out goo is your printer's perfect fit.
joint flange | PETG | Screw the small plate onto the block with one screw. It should pull down tight with no wobble and no cracking.
joint boss | PETG | The partner block for the plate test above.
dbore torque | PETG | Grown-up pushes this onto a motor shaft and twists HARD, twice as hard as driving ever will. If it never slips, wheels are safe.
axle stub | PETG | Spin the ring on the peg a few hundred times with some pressure. It should stay smooth, not sloppy.
bushing ring | PETG | The spinning ring for the peg test above.
snap pair | PETG | Click the two pieces together and apart ten times. The little hook must survive and still hold on.
bayonet pair | PETG | Twist the ring onto the stub a quarter turn - it should lock with a nice click and not pull straight off.
switch pocket | PETG | Grown-up seats one bumper switch in the pocket: it must click when pressed and spring back, never jammed.
tire fit | TPU+PETG | Stretch the mini tire onto the mini wheel. Snug and even = your big tires will fit too.
pcb clamp | PETG | Rest the little green safety board on the pegs and screw the bar over it. Held gently, nothing bending.

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

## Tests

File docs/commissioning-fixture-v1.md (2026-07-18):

# RB-FIXTURE-V1 — unpowered commissioning fixture

Status: **design and hardware-free validation only; no physical pass is bundled.**

This one-plate fixture makes the first Pico safety observations repeatable without
a battery, motor, or MDDS10. It uses the six real NC bumper switches, real IDEC
E-stop, and real Panasonic relay, but the headered Pico is a dedicated fixture
part. Passing this guide never authorizes powered motion.

## Boundary

- F1–F3 are mechanical, continuity, and USB-logic work.
- F4 adds a **12.0 V, 0.20 A current-limited bench supply** only after GP11 is low.
- Current firmware deliberately keeps GP11 low. This negative-control witness
  requires the relay and lamp to stay off.
- Remove 12 V before every Pico reset, flash, unplug, or wiring change. Apply USB
  first and 12 V last. Driver reset behavior is not a safety control.

## Print one part

Export `cad/openscad/commissioning_fixture_v1.scad` as PETG. The plate is
232 × 210 × 79 mm overall. Print its component face on the P1S plate with the four
hollow feet upward; no supports. Flip after printing. The 75 mm feet leave 6.3 mm
beyond the registered 68.7 mm E-stop-plus-terminal envelope. CAD clearance is not
delivered-part fit evidence.

## Parts

Availability references were checked 2026-07-17. Reused parts return to the robot
only after inspection. M3 × 12 screws and nylocs are fixture-only and do not alter
the robot's single-M3 × 8 rule.

| ID | Item | Exact part / source | Qty | Use |
| --- | --- | --- | ---: | --- |
| `PICO` | Raspberry Pi Pico 2 with headers | [SC1632](https://pip.raspberrypi.com/categories/1005-raspberry-pi-pico-2) | 1 | fixture; dedicated fixture board; never the production robot Pico |
| `DEBUG_PROBE` | Raspberry Pi Debug Probe | [SC0889](https://www.raspberrypi.com/documentation/microcontrollers/debug-probe.html) | 1 | fixture; use only the three-wire UART U cable; no SWD connection during observations |
| `BREADBOARD` | 830-point solderless breadboard | [BusBoard BB830 or Adafruit 239](https://www.adafruit.com/product/239) | 1 | fixture; attach with the supplied adhesive backing |
| `BUMP_1` | Omron SPST-NC bumper switch | [D2HW-C202MR](https://omronfs.omron.com/en_US/ecb/products/pdf/en-d2hw.pdf) | 1 | reuse |
| `BUMP_2` | Omron SPST-NC bumper switch | [D2HW-C202MR](https://omronfs.omron.com/en_US/ecb/products/pdf/en-d2hw.pdf) | 1 | reuse |
| `BUMP_3` | Omron SPST-NC bumper switch | [D2HW-C202MR](https://omronfs.omron.com/en_US/ecb/products/pdf/en-d2hw.pdf) | 1 | reuse |
| `BUMP_4` | Omron SPST-NC bumper switch | [D2HW-C202MR](https://omronfs.omron.com/en_US/ecb/products/pdf/en-d2hw.pdf) | 1 | reuse |
| `BUMP_5` | Omron SPST-NC bumper switch | [D2HW-C202MR](https://omronfs.omron.com/en_US/ecb/products/pdf/en-d2hw.pdf) | 1 | reuse |
| `BUMP_6` | Omron SPST-NC bumper switch | [D2HW-C202MR](https://omronfs.omron.com/en_US/ecb/products/pdf/en-d2hw.pdf) | 1 | reuse |
| `ESTOP_SENSE_SIM` | breadboard SPST logic control | fixture-only switch or jumper | 1 | fixture; separate logic simulation; not an E-stop contact |
| `RESET_BUTTON` | breadboard momentary SPST logic control | fixture-only switch or jumper | 1 | fixture |
| `CHARGER_SIM` | breadboard SPST logic control | fixture-only switch or jumper | 1 | fixture; closed is charger absent; open is charger present because GP10 uses the firmware pull-up |
| `ESTOP` | IDEC dual-NC emergency stop | [XW1E-BV402M-R](https://us.idec.com/idec-us/en/USD/medias/IDEC-XA-XW-EMO-Datasheet.pdf) | 1 | reuse; both NC channels are physically in series; test each channel power-off before 12 V |
| `DRIVER` | Adafruit MOSFET Driver | [5648](https://learn.adafruit.com/adafruit-mosfet-driver/pinouts) | 1 | fixture; non-isolated low-side switch; integral flyback diode; output + is V+ and output - is switched ground |
| `RELAY` | Panasonic sealed SPST-NO relay | CB1A-R-M-12V | 1 | reuse; 12 V, 134 mA coil; fixture uses the real robot relay |
| `LAMP` | Bulgin green 12 V LED indicator | [DX06WG012B](https://www.bulgin.com/pdf/pdf.php?sku=DX06WG012B) | 1 | fixture; witness load on relay NO only |
| `BENCH_12V` | current-limited bench supply | user bench supply | 1 | fixture; set 12.0 V and 0.20 A before connecting; no battery |
| `WAGO` | two-conductor lever connector | [221-412/K007-0000](https://www.wago.com/us/wire-splicing-connectors/compact-splicing-connector/p/221-412) | 10 | fixture |
| `WIRE` | 22 AWG solid-core breadboard wire set | [Adafruit 1311](https://www.adafruit.com/product/1311) | 1 | fixture; fixture-only low-current wiring; do not infer a production harness release |
| `UART_CABLE` | three-pin JST-SH socket cable | [Adafruit 3893](https://www.adafruit.com/product/3893) | 1 | fixture; optional spare/adapter; Debug Probe U cable remains the UART baseline |
| `PLATE` | printed fixture plate | cad/openscad/commissioning_fixture_v1.scad | 1 | fixture; PETG; 232 x 210 x 79 mm overall; no supports |
| `FIXTURE_FASTENERS` | fixture-only fasteners | M3 x 12 SHCS plus M3 nyloc nuts | 12 | fixture; temporary fixture hardware, deliberately distinct from the robot's M3 x 8 single-SKU system |

## Assemble with no power

1. Flip the print and confirm all four feet sit without rocking.
2. Apply `commissioning/generated/fixture-v1-labels.svg` at 100% scale.
3. Stick down the breadboard. Mount the six Omrons with M3 × 12 screws and nylocs.
4. Tie the driver and relay through their slots. Fit E-stop and lamp with their nuts.
5. Put the dedicated SC1632 Pico on the breadboard. Use only the Debug Probe UART
   U cable: GP0 TX to probe RX, GP1 RX to probe TX, and ground to ground. No SWD.
6. Build separate GP8 E-stop-sense, GP9 reset, and GP10 charger-simulation controls.
   They are logic simulations, not physical safety paths.

## Wire these nets exactly

The Adafruit 5648 is a **non-isolated low-side driver**. Output `+` is V+, output
`-` is switched ground, and all grounds are common.

| Net | Domain | Endpoints |
| --- | --- | --- |
| `GND_COMMON` | `ground` | `PICO.GND` -> `DEBUG_PROBE.GND` -> `DRIVER.GND` -> `BENCH_12V.NEG` -> `BUMP_1.COM` -> `BUMP_2.COM` -> `BUMP_3.COM` -> `BUMP_4.COM` -> `BUMP_5.COM` -> `BUMP_6.COM` -> `ESTOP_SENSE_SIM.COM` -> `RESET_BUTTON.COM` -> `CHARGER_SIM.COM` -> `LAMP.NEG` |
| `UART_TX` | `PICO_LOGIC` | `PICO.GP0` -> `DEBUG_PROBE.RX` |
| `UART_RX` | `PICO_LOGIC` | `PICO.GP1` -> `DEBUG_PROBE.TX` |
| `BUMP_1_NC` | `PICO_LOGIC` | `PICO.GP2` -> `BUMP_1.NC` |
| `BUMP_2_NC` | `PICO_LOGIC` | `PICO.GP3` -> `BUMP_2.NC` |
| `BUMP_3_NC` | `PICO_LOGIC` | `PICO.GP4` -> `BUMP_3.NC` |
| `BUMP_4_NC` | `PICO_LOGIC` | `PICO.GP5` -> `BUMP_4.NC` |
| `BUMP_5_NC` | `PICO_LOGIC` | `PICO.GP6` -> `BUMP_5.NC` |
| `BUMP_6_NC` | `PICO_LOGIC` | `PICO.GP7` -> `BUMP_6.NC` |
| `ESTOP_SENSE_SIM` | `PICO_LOGIC` | `PICO.GP8` -> `ESTOP_SENSE_SIM.SW` |
| `RESET_SIM` | `PICO_LOGIC` | `PICO.GP9` -> `RESET_BUTTON.SW` |
| `CHARGER_SIM` | `PICO_LOGIC` | `PICO.GP10` -> `CHARGER_SIM.SW` |
| `RELAY_LOGIC` | `PICO_LOGIC` | `PICO.GP11` -> `DRIVER.IN` |
| `12V_POS` | `BENCH_12V` | `BENCH_12V.POS` -> `ESTOP.NC1_IN` -> `RELAY.COM` |
| `ESTOP_SERIES` | `BENCH_12V` | `ESTOP.NC1_OUT` -> `ESTOP.NC2_IN` |
| `DRIVER_VPLUS` | `BENCH_12V` | `ESTOP.NC2_OUT` -> `DRIVER.VPLUS` -> `RELAY.COIL_HIGH` |
| `DRIVER_OUT` | `BENCH_12V_SWITCHED` | `DRIVER.OUT` -> `RELAY.COIL_LOW` |
| `RELAY_NO_LAMP` | `BENCH_12V_SWITCHED` | `RELAY.NO` -> `LAMP.POS` |

```text
12V_POS -> IDEC NC1 -> IDEC NC2 -> DRIVER.VPLUS / RELAY.COIL_HIGH
PICO.GP11 -> DRIVER.IN
DRIVER.OUT -> RELAY.COIL_LOW
12V_POS -> RELAY.COM -> RELAY.NO -> LAMP -> GND_COMMON
```

The driver carries the flyback diode across V+/OUT. **Reverse polarity can
forward-bias it.** Meter polarity before 12 V and keep the 0.20 A limit set. Do
not discover polarity with sparks, however festive.

## Firmware pins

`python3 commissioning/fixture.py --check` parses the authoritative Pico target.

| Signal | Pico pin |
| --- | ---: |
| `uart_tx` | GP0 |
| `uart_rx` | GP1 |
| `bumper_1` | GP2 |
| `bumper_2` | GP3 |
| `bumper_3` | GP4 |
| `bumper_4` | GP5 |
| `bumper_5` | GP6 |
| `bumper_6` | GP7 |
| `estop_sense` | GP8 |
| `reset` | GP9 |
| `charger_sense` | GP10 |
| `relay_enable` | GP11 |

## F1 — mechanical, no power

- [ ] Plate is flat; feet are uncracked; labels are legible.
- [ ] Tallest underside part has at least 5 mm table clearance.
- [ ] Switches operate without moving their mounts.
- [ ] Pico is the fixture SC1632, not production Pico.
- [ ] Battery, motors, and MDDS10 are absent.

## F2 — continuity, no power

- [ ] Each bumper is closed at rest and opens when pressed.
- [ ] IDEC NC1 opens when pressed; release/twist, then repeat for NC2.
- [ ] The series coil path opens when either NC channel opens.
- [ ] No Pico GPIO has continuity to a 12 V net.
- [ ] 12V_POS is not shorted to ground; loose supply leads meter with correct polarity.

The series E-stop path proves each contact individually only while unpowered. It
cannot create two independent powered channel results. Record that limitation.

## F3 — USB logic and UART

1. Leave 12 V disconnected. Connect Pico USB and Debug Probe USB separately.
2. Observe 115200-baud status and measure GP11 low.
3. Open one bumper at a time; record exact zone identity. Hold one open to observe
   broken-wire behavior.
4. Exercise GP8, GP9, and GP10 separately. GP10 closed to ground means charger
   absent; open means charger present through the firmware pull-up.
5. Send fixed-contract status/heartbeat/drive frames. Capture clamps and latches,
   but do not record relay or motor behavior.
6. Confirm GP11 stayed low. Disconnect USB before changing wires.

## F4 — 12 V negative control

1. Re-run F2. Set the disconnected supply to 12.0 V and **0.20 A maximum**. Turn it
   off and meter its polarity again.
2. Start USB logic, wait for stable status, and measure GP11 low.
3. With Pico stable, connect 12V_POS and ground while the supply is off, then turn
   it on. Never reset or flash the Pico while 12 V is present.
4. Only the driver's small idle/indicator current is expected. The 134 mA relay
   coil must not energize and the roughly 20 mA lamp must remain dark.
5. If the relay clicks, lamp lights, current limit trips, or current approaches the
   coil load, turn 12 V off immediately and record failure.
6. Press the physical E-stop only to confirm the already-off feed is removed. This
   is not a powered de-energization timing result.
7. Turn off and disconnect 12 V before stopping USB logic.

## This fixture cannot pass

- Coil actuation, a positive lamp result, or powered E-stop timing with the current
  fail-stopped target.
- Production conditioned inputs, relay driver, contact wetting, fuses, harness,
  motor outputs, encoders, battery, or thermal behavior.
- Independent powered proof of the two series E-stop channels.
- Any physical commissioning result without exact first-article measurements.

`commissioning/fixture-v1.json` is authoritative. Generated prose, labels, and
SCAD data are conveniences; `--check` makes drift loud.

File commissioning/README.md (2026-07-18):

# Executable commissioning and evidence bundles

The 27-step [`plan-v2.json`](plan-v2.json) is the physical release procedure.
[`commission.py`](commission.py) captures each first article in a private,
content-addressed bundle and can seal a complete bundle with an OpenSSH
signature. It does not include or invent a physical pass.

Start with the full [first-article evidence guide](../docs/first-article-evidence.md).
The short command map is:

```bash
python3 commissioning/fixture.py --check
python3 commissioning/commission.py list
python3 commissioning/commission.py show C001
python3 commissioning/commission.py --bundle output/commissioning/RB-001 init \
  --robot-serial RB-001 --operator Brian \
  --source-ref refs/tags/REPLACE_WITH_RELEASE_TAG
python3 commissioning/commission.py --bundle output/commissioning/RB-001 record C001 \
  --result pass --operator Brian \
  --measure battery_serial=... --measure harness_revision=... \
  --attach first_article_identity_photo=/absolute/path/labels.jpg
python3 commissioning/commission.py --bundle output/commissioning/RB-001 report
```

`show` prints a step's exact measurements, evidence roles, and predicates.
`record` imports each file into `objects/sha256/`; paths are never kept as
evidence. A later event supersedes an earlier event for the same step, so normal
FAIL -> repair -> PASS work remains visible.

Final sealing and independent verification require an out-of-repository trust
policy:

```bash
python3 commissioning/commission.py --bundle output/commissioning/RB-001 seal \
  --signing-key /secure/path/commissioning_ed25519 \
  --signer brian@example.com
python3 commissioning/commission.py --bundle /received/RB-001 \
  --source-repo /clean/robot-clone verify \
  --allowed-signers /secure/policy/allowed_signers \
  --signer brian@example.com --robot-serial RB-001
```

The final command means only that the expected signer attested to the exact
bundle bytes for the expected robot and committed source. It does not prove a
measurement was honestly taken, and it never replaces the harness or powered
release gates. A cute robot with borrowed paperwork remains a cute robot with
forged paperwork—now with a much easier audit trail.

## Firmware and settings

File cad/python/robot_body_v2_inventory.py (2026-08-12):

"""Registered inventory for the v2 printed-only body (Phase 2, D025-D028).

This module is the single source of truth for the v2 layout's envelopes
and the printed-part registry. It is consumed by:

- `packing_study_printed_only.py` — the box-level screen;
- `robot_body_v2.py` — the v2 BREP production/prototype geometry;
- `validate_robot_body_v2.py` — the inventory-driven validator,
  whose contract is that an envelope absent from THIS
  registry is itself a failure.

Every envelope entry records its `basis`: which `Params` fields or verified
helpers it derives from. Estimate tags are forbidden by the validator gate;
the current registry has none and the D027 production CAD gate is closed.

The printed-part registry implements D028: each part declares quantity,
material, print orientation, and a justification for existing as a
separate part (service access, material/color change, orientation
conflict, calibration interface, or wear-part replaceability). Parts
marked `merge_candidate` are owed merges that bring the draft count down
to the hard budget of 40.
"""

from __future__ import annotations

import math
import sys
from dataclasses import dataclass
from pathlib import Path

sys.path.insert(0, str(Path(__file__).parent))
import robot_body as rb  # noqa: E402

P = rb.Params()

# ---------------------------------------------------------------------------
# Verified datums (review round 3; see the plan's review-outcome section).
# ---------------------------------------------------------------------------
WALL = P.wall
BODY_L, BODY_W = 238.0, 220.0
IX, IY = BODY_L / 2 - WALL, BODY_W / 2 - WALL            # interior walls
ROOF_FLAT_X = BODY_L / 2 - P.body_edge_radius            # rollover-limited roof flat
ROOF_FLAT_Y = BODY_W / 2 - P.body_edge_radius
TRAY_TOP = P.body_bottom                                  # 49 (verified)
MDDS_TOP = (rb.motor_controller_plate_top_z(P) + P.mdds10_standoff_height
            + P.mdds10_above_pcb)                         # 76.275 (verified)
THERM_TOP = MDDS_TOP + P.mdds10_airflow_height            # 86.275
SHELF0, SHELF1 = THERM_TOP, THERM_TOP + 4.0
PI_TOP = SHELF1 + P.pi_clearance_height                   # 118.275
HAT_TOP = PI_TOP + 22.0                                   # 140.275 (96 x 74 x 22 reserve)
CLEAR_MARGIN = 3.0
DROP_V1 = 131.6                                           # pan_servo_fit bbox min Z at H=121 (verified)
DH = math.ceil(HAT_TOP + CLEAR_MARGIN - DROP_V1)          # 12, computed
BODY_H = 121.0 + DH                                       # 133
Z_TOP = P.body_bottom + BODY_H                            # 182
Z_ROOF_IN = Z_TOP - WALL
DROP0 = DROP_V1 + DH                                      # 143.6
DECK0, DECK1 = P.power_deck_z - 2.0, P.power_deck_z + 2.0  # 102..106 (verified)
FRONT_AXLE_X, REAR_AXLE_X = -74.0, 74.0                   # wheels >= 2 mm inside shell
ESTOP = (59.0, 56.0)
ESTOP_R = P.estop_backing_outer_radius
MIC = (60.0, -25.0)
MIC_R = (P.mic_array_diameter + 2 * P.mic_cradle_outer_margin) / 2
ESTOP_BODY_Z0 = Z_ROOF_IN - P.estop_body_depth            # 130.1
ESTOP_TERM_Z0 = ESTOP_BODY_Z0 - P.estop_terminal_service_depth  # 110.1

MIN_MARGIN = 2.0      # minimum clearance between distinct assemblies and to walls


# ---------------------------------------------------------------------------
# Envelope registry.
# ---------------------------------------------------------------------------
@dataclass(frozen=True)
class Envelope:
    name: str
    kind: str      # "keepout" | "item" | "service"
    group: str
    box: tuple     # (x0, x1, y0, y1, z0, z1)
    basis: str     # Params/helper derivation, or "ESTIMATE: ..."
    mirror_y: bool = False


E = Envelope
ENVELOPES = [
    # -- structure and purchased-part keepouts --
    E("front_bay", "keepout", "shellF", (-IX, -104, -IY, IY, TRAY_TOP, Z_TOP),
      "modeled: fascia panel recess + front ToF pocket depth (robot_body_v2)"),
    E("rear_en2_N", "keepout", "rear_en2_N", (IX - 28, IX, 23, 47, 115, 145),
      "charge_jack_overall_depth 20.07 + wire bend; rear panel + connector holes modeled"),
    E("rear_mute_S", "keepout", "rear_mute_S",
      (IX - (P.mute_switch_body_depth + P.mute_switch_terminal_service_depth), IX, -47, -23, 115, 145),
      "mute_switch_body_depth 26 + mute_switch_terminal_service_depth 16"),
    E("front_arch", "keepout", "shellF", (FRONT_AXLE_X - 43, FRONT_AXLE_X + 43, 96, IY, TRAY_TOP, 109),
      "modeled: circular arch opening r47 following the tire; wall band Y 94..112", mirror_y=True),
    E("rear_arch", "keepout", "shellR", (REAR_AXLE_X - 43, IX, 96, IY, TRAY_TOP, 109),
      "modeled: circular arch opening r47 following the tire (rear)", mirror_y=True),
    E("front_pod", "keepout", "shellF", (FRONT_AXLE_X - 22, FRONT_AXLE_X + 22, 86, IY, TRAY_TOP, 95),
      "modeled: pod skeleton with integral printed stub axle (robot_body_v2)", mirror_y=True),
    E("motor", "keepout", "shellR",
      (REAR_AXLE_X - 12.5, REAR_AXLE_X + 12.5, P.motor_face_y - P.motor_body_length, IY, 53.5, 78.5),
      "motor_body_diameter 25 / motor_body_length 68.45 / motor_face_y 110 at axle Z 66", mirror_y=True),
    E("neck_drop", "keepout", "head", (-55.8, -12.0, -8.5, 8.5, DROP0, Z_TOP),
      "pan_servo_fit bbox (x -53.8..-14, y +/-6.5, z from 131.6 at H=121) "
      "+ 2 mm clearance, tracking body height"),
    E("head_sweep_1", "keepout", "head", (-100.6, 48.6, -25.0, 25.0, 212.0, 294.0),
      "pan-sweep disc r=78.7 about the neck axis, chord box |y|<=25"),
    E("head_sweep_2", "keepout", "head", (-89.1, 37.1, -47.0, 47.0, 212.0, 294.0),
      "pan-sweep chord box |y|<=47"),
    E("head_sweep_3", "keepout", "head", (-74.5, 22.5, -62.0, 62.0, 212.0, 294.0),
      "pan-sweep chord box |y|<=62"),
    E("head_sweep_4", "keepout", "head", (-36.5, -15.5, -78.0, 78.0, 212.0, 294.0),
      "pan-sweep chord box |y|<=78"),
    E("estop_press", "keepout", "estop", (ESTOP[0] - 14, ESTOP[0] + 14, ESTOP[1] - 14, ESTOP[1] + 14, Z_TOP, Z_TOP + 48),
      "slap-access sweep: the 40 mm mushroom footprint + 8 finger margin, "
      "solid-free; mushroom edge clears the head sweep disc by 3.1 and the "
      "press corner by 3.8 (finding #11: E-stop moved from (55,52))"),
    E("neck_collar_W", "keepout", "head", (P.neck_x - 30, P.neck_x - 20.5, -30, 30, Z_TOP - 8, Z_TOP),
      "collar ring segment (od 60 / id 41); the neck bore stays open"),
    E("neck_collar_E", "keepout", "head", (P.neck_x + 20.5, P.neck_x + 30, -30, 30, Z_TOP - 8, Z_TOP),
      "collar ring segment"),
    E("neck_collar_N", "keepout", "head", (P.neck_x - 20.5, P.neck_x + 20.5, 20.5, 30, Z_TOP - 8, Z_TOP),
      "collar ring segment"),
    E("neck_collar_S", "keepout", "head", (P.neck_x - 20.5, P.neck_x + 20.5, -30, -20.5, Z_TOP - 8, Z_TOP),
      "collar ring segment"),
    E("estop_panel", "keepout", "estop",
      (ESTOP[0] - ESTOP_R, ESTOP[0] + ESTOP_R, ESTOP[1] - ESTOP_R, ESTOP[1] + ESTOP_R, Z_TOP - 20, Z_TOP),
      "estop_backing_outer_radius 33"),
    E("estop_body", "keepout", "estop",
      (ESTOP[0] - 20, ESTOP[0] + 20, ESTOP[1] - 20, ESTOP[1] + 20, ESTOP_BODY_Z0, Z_TOP),
      "estop_body_pass_diameter 40 / estop_body_depth 48.7"),
    E("estop_term", "keepout", "estop",
      (ESTOP[0] - 20, ESTOP[0] + 20, ESTOP[1] - 20, ESTOP[1] + 20, ESTOP_TERM_Z0, ESTOP_BODY_Z0),
      "estop_terminal_service_depth 20"),
    E("mic", "keepout", "mic",
      (MIC[0] - MIC_R, MIC[0] + MIC_R, MIC[1] - MIC_R, MIC[1] + MIC_R, Z_TOP - 20, Z_TOP),
      "mic_array_diameter 70 + mic_cradle_outer_margin 3"),
    E("vent", "keepout", "vent", (30, 90, -96, -65, Z_TOP - 10, Z_TOP),
      "design: slim south vent strip (D027 delta)"),
    E("speaker", "keepout", "speaker", (-48, 22, 76, 106, 115, 145),
      "speaker 70x30x17 + clearance; shell ledges/gussets modeled (robot_body_v2)", mirror_y=True),
    E("mdds10_thermal", "keepout", "mddsT", (-101, -34, -50.5, 50.5, MDDS_TOP, THERM_TOP),
      "mdds10_airflow_height 10 over the board extent"),
    E("sweep_en2", "keepout", "rear_en2_N", (BODY_L / 2 + 0.1, BODY_L / 2 + 45, 27, 43, 122, 138),
      "charge plug insertion sweep outside the panel face: "
      "charge_jack_plug_service_length 39.9, solid-free"),
    E("sweep_mute", "keepout", "rear_mute_S", (BODY_L / 2 + 0.1, BODY_L / 2 + 40, -43, -27, 122, 138),
      "mute actuation finger sweep outside the panel face, solid-free"),

    # -- placed items and their service volumes --
    E("mdds10", "item", "mdds", (-101, -34, -50.5, 50.5, 64, MDDS_TOP),
      "MDDS10 board 66.8x101 + components, PCB bottom at Z 64 on the tower "
      "standoffs (motor_controller_plate_top_z chain); plate, standoffs, and "
      "shelf are controller_tower printed geometry"),
    E("mdds10_svc", "service", "mdds", (-89, -45, 62, 86, 58, MDDS_TOP),
      "mdds10_terminal_service 24x44 facing NORTH; floor at Z 58 (terminals "
      "live at board level 64+, leaving 6 for wire sweep) so the pod base "
      "flange plane below stays clear"),
    E("pi_shelf", "item", "pi", (-101, -5, -34, 34, SHELF1, PI_TOP),
      "pi_clearance 96x68x28 seated on the controller_tower shelf plate "
      "(the plate itself is printed geometry at the thermal ceiling)"),
    E("pi_port_svc", "service", "pi", (-5, 19, -30, 30, SHELF1, PI_TOP),
      "cable spec: right-angle USB-A/RJ45 plug bodies (14) + 10 bend allowance east of the port edge"),
    E("ai_hat2", "item", "pi", (-101, -5, -37, 37, PI_TOP, HAT_TOP),
      "cad-mechanical-plan.md: AI HAT+ 2 clearance 96 x 74 x 22; stacked above the Pi band (conservative)"),
    E("pico_floor", "item", "pico", (-28, 34, 47, 80, 53, 67),
      "pico2_clearance 62x33x14 seated on 4 mm tray bosses (bosses are tray geometry)"),
    E("pico_usb_svc", "service", "pico", (34, 54, 58.5, 68.5, 53, 67),
      "pico2_usb_notch 20x10, facing EAST"),
    E("pico_swd_svc", "service", "pico", (-26, -6, 52, 75, 63, 80),
      "tool spec: SWD pogo/plug top access, 17 above the board + finger reach"),
    E("battery_pack", "item", "bat", (-25.3, 85.3, -38.1, 38.1, 52, 79),
      "BLF-1203AB 110x75x27 rotated + 0.6 side clearance, on 3 mm tray pads; "
      "cradle rails/stops are tray geometry, not envelope"),
    E("bat_leads", "service", "bat", (85, 113, -27, 27, 65, 79),
      "battery_lead_service 28x54x14 at the pack rear"),
    E("riser", "service", "bat", (100, 113, 25, 45, 65, 115),
      "round-4 carry-in: lead riser through the deck notch to the EN2"),
    E("deck_mid", "item", "deck", (24, 113.8, -67, 23, DECK0, DECK1),
      "deck plate at power_deck_z +/- 2 (verified); riser notch splits the segments"),
    E("deck_n2", "item", "deck", (56, 98, 23, 47, DECK0, DECK1),
      "deck segment west of the riser notch; NW trimmed (floor below is battery+Pico, nothing to carry)"),
    E("deck_n1", "item", "deck", (56, 113.8, 47, 67, DECK0, DECK1), "deck north segment, NW trimmed"),
    E("fuse5045", "item", "fuse",
      (24, 24 + P.power_distribution_width, -67, -67 + P.power_distribution_length,
       DECK1, DECK1 + P.power_distribution_height),
      "Blue Sea 5045 92.5x43.8x32.5 (power_distribution_*), lengthwise on the deck south half"),
    E("fuse_wire_svc", "service", "fuse",
      (24, 24 + P.power_distribution_width, -67 - P.power_distribution_wire_service_length, -67,
       DECK1, DECK1 + P.power_distribution_height),
      "power_distribution_wire_service_length 22 at FULL block height (round-3 fix)"),
    E("relay_bracket", "item", "relay",
      (-46, -46 + P.motor_cutoff_bracket_length, -90, -90 + P.motor_cutoff_bracket_width, TRAY_TOP, 51),
      "motor_cutoff_bracket 52x22 on the floor (round-4 carry-in: exact volumes)"),
    E("relay_body", "item", "relay",
      (-36, -36 + P.motor_cutoff_body_length, -90, -90 + P.motor_cutoff_body_width, 51,
       51 + P.motor_cutoff_body_height),
      "motor_cutoff_body 26x22x25"),
    E("relay_term_svc", "service", "relay",
      (-36, -36 + P.motor_cutoff_body_length, -90, -90 + P.motor_cutoff_body_width, 76,
       76 + P.motor_cutoff_terminal_service_height),
      "motor_cutoff_terminal_service_height 16"),
    E("regD24_under", "item", "regD24",
      (92, 92 + P.pi_regulator_width, -50, -50 + P.pi_regulator_length, 90.7, 98.7),
      "D24V90F5 40.6x20.3 rotated, seated component-side-down in the D049 "
      "under-deck bay (PCB top on the bay pads at Z 98.7; pads, walls, and "
      "the two M3 edge-clamp stations are deck geometry)"),
    E("regD24_term_S", "service", "regD24", (94, 110, -60, -50, 86.7, 98.7),
      "pi_regulator_terminal_service 10x16x12, south end (rides the D049 "
      "seated-board height)"),
    E("regD24_term_N", "service", "regD24", (94, 110, -9.4, 0.6, 86.7, 98.7),
      "pi_regulator_terminal_service 10x16x12, north end (round-3 fix; "
      "rides the D049 seated-board height)"),
    E("regD36_under", "item", "regD36",
      (60, 60 + P.servo_regulator_length, -6, -6 + P.servo_regulator_width, 89.2, 98.7),
      "D36V50F6 25.4 sq, seated component-side-down in the D049 dual-footprint "
      "bay (PCB top on the bay pads at Z 98.7; the D36V28F6-class alternate "
      "shares the SE datum and both clamp stations, dims PROVISIONAL)"),
    E("regD36_wire_W", "service", "regD36",
      (60 - P.servo_regulator_wire_service_length, 60, -2, 20, 86.7, 98.7),
      "servo_regulator_wire_service 14x22x12 facing WEST (round-3 fix: east "
      "exits the body; rides the D049 seated-board height)"),
    E("rail_L", "item", "rail_L", (38, 78, -60, -46, 96, DECK0),
      "signal/audio harness channel under the deck (v2: deck rib per D028); shortened clear of the SW and SE deck towers"),
    E("rail_R", "item", "rail_R", (26, 96, 41, 55, 96, DECK0),
      "switched-power harness channel under the deck (v2: deck rib per D028)"),
]

# Intended support/abutment contacts: EXACT envelope-name pairs. These waive
# only the 2 mm margin; a volumetric overlap is never waived by this list.
ALLOWED_TOUCH = {
    frozenset(("fuse5045", "deck_mid")), frozenset(("fuse5045", "deck_n2")),
    frozenset(("fuse_wire_svc", "deck_mid")),
    frozenset(("regD24_under", "deck_mid")), frozenset(("regD24_term_S", "deck_mid")),
    frozenset(("regD24_term_N", "deck_mid")), frozenset(("regD36_under", "deck_mid")),
    frozenset(("regD36_wire_W", "deck_mid")),
    frozenset(("rail_L", "deck_mid")), frozenset(("rail_R", "deck_mid")),
    frozenset(("rail_R", "deck_n2")), frozenset(("rail_R", "deck_n1")),
    frozenset(("riser", "rear_en2_N")), frozenset(("riser", "deck_mid")),
    frozenset(("riser", "deck_n1")), frozenset(("riser", "deck_n2")),
    frozenset(("mdds10", "front_bay")), frozenset(("mdds10_svc", "front_bay")),
    frozenset(("mdds10_svc", "front_pod")),
    frozenset(("route_motor_leads", "rail_R")), frozenset(("route_motor_leads", "rail_L")),
    frozenset(("route_speaker_feed_b", "rail_L")), frozenset(("route_speaker_feed_b", "deck_mid")),
    frozenset(("route_speaker_feed_a", "speaker")),
    frozenset(("route_camera_fpc_1", "pi_port_svc")), frozenset(("route_camera_fpc_1", "deck_mid")),
    frozenset(("mdds10_thermal", "mdds10")), frozenset(("mdds10_thermal", "pi_shelf")),
}


def boxes():
    """Expand mirrors into the (name, kind, group, x0, x1, y0, y1, z0, z1) tuples."""
    out = []
    for e in ENVELOPES:
        out.append((e.name, e.kind, e.group, *e.box))
        if e.mirror_y:
            x0, x1, y0, y1, z0, z1 = e.box
            out.append((e.name + "~m", e.kind, e.group + "~m", x0, x1, -y1, -y0, z0, z1))
    return out


# ---------------------------------------------------------------------------
# Printed-part registry (D028/D034): production inventory, material policy,
# and optional cosmetics. Material family, mechanical role, and visible color
# are deliberately separate; "teal PETG" is no longer a material science
# category invented by a cheerful little rover.
# ---------------------------------------------------------------------------
PART_BUDGET = 40

MATERIAL_FAMILIES = {"PLA", "PETG", "TPU"}
MECHANICAL_ROLES = {
    "visible_cosmetic", "qualified_enclosure", "structure",
    "wear_motion", "safety_service", "flexible", "optical",
}
QUALIFICATION_POLICIES = {"direct", "physical-gate-required", "fixed-PETG"}
QUALIFICATION_STATUSES = {"not-required", "open", "passed"}

# Theme slots control appearance only. They never authorize a material-family
# change. Production PETG is intentionally restricted to white/black/red.
DEFAULT_THEME = {
    "body_primary": {"name": "Cream", "hex": "#F0DEC2", "role": "visible body and qualified head"},
    "top_accent": {"name": "Teal", "hex": "#0B8392", "role": "optional cosmetic lid skin"},
    "dark_panel": {"name": "Charcoal", "hex": "#15171B", "role": "visible panels and faceplate"},
    "light_diffuser": {"name": "Translucent lime", "hex": "#D7FF52", "role": "eye and status diffusers"},
    "structure_light": {"name": "White", "hex": "#F2F2EE", "role": "general PETG structure"},
    "structure_wear": {"name": "Black", "hex": "#15171B", "role": "PETG motion and wear structure"},
    "safety_service": {"name": "Red", "hex": "#C51E2A", "role": "PETG service retainers"},
    "flexible_dark": {"name": "Charcoal", "hex": "#15171B", "role": "TPU impact and traction"},
}
PETG_COLOR_SLOTS = {"structure_light", "structure_wear", "safety_service"}
SUPPORT_EXCEPTIONS: dict[str, str] = {}

@dataclass(frozen=True)
class PrintedPart:
    name: str
    qty: int
    material_family: str  # requested family: PLA | PETG | TPU
    mechanical_role: str
    color_slot: str
    qualification: str    # direct | physical-gate-required | fixed-PETG
    orientation: str     # declared print orientation (D028 audits run in it)
    justification: str   # why this exists as a separate part
    qualification_status: str = "not-required"
    fallback_material_family: str = ""
    fallback_color_slot: str = ""
    installed_qty: int | None = None
    optional: bool = False
    merge_candidate: str = ""  # non-empty: owed merge target to reach the budget

    @property
    def effective_material_family(self) -> str:
        if self.qualification == "physical-gate-required" and self.qualification_status != "passed":
            return self.fallback_material_family
        return self.material_family

    @property
    def effective_color_slot(self) -> str:
        if self.qualification == "physical-gate-required" and self.qualification_status != "passed":
            return self.fallback_color_slot
        return self.color_slot

    @property
    def functional_installed_qty(self) -> int:
        if self.optional:
            return 0
        return self.qty if self.installed_qty is None else self.installed_qty

    @property
    def spare_qty(self) -> int:
        if self.optional:
            return 0
        return self.qty - self.functional_installed_qty
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

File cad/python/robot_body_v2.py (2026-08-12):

"""v2 BREP packing-model skeleton for the printed-only body (Phase 2).

Builds the primary printed solids of the D027 footprint — one-piece tray,
shell, and lid at 238 x 220 x 133, the two TPU bumper C-halves, and the
two front pods with integral printed stub axles — directly from the
registered inventory (`robot_body_v2_inventory.py`). The inventory-driven
validator checks these for interference against every registered
envelope, bed fit, and the D028 printability audits.

Current model scope:
- Tray: rounded plan, wheel-well notches, envelope-cleared deck towers,
  up-opening motor-saddle troughs, battery cradle (pads, side rails,
  low end stops clear of the lead corridor), Pico seat bosses, and six
  bumper-switch pockets molded into the underside (D028 merge: the six
  v1 switch plates are gone).
- Shell: offset-shelled 3.2 mm walls with the 12 mm top rollover, lid
  recess + opening with a seating ledge, tire-following CIRCULAR wheel
  arches (the round crown prints as a short bridge and matches the
  concept, replacing the earlier oversized peaked cuts), and mullioned
  fascia/rear openings — every sub-span <= 30 mm bridges cleanly and the
  mullions hide behind the fascia and rear panels.
- Lid: complete white-PETG structural panel with the E-stop bore, mic slot
  field, vent slots, and four blind pockets for an optional cosmetic skin.
- Optional lid skin: thin PLA accent with copied airflow/acoustic openings,
  generous E-stop/neck/screw clearance, and four captive shallow snap tabs.
- Bumper C-halves (TPU): open-bottom U cross-section (D028 rule 8, no
  bridged cavities), wheel cutouts with concealed low inboard bridges
  keeping each half one piece; printed upside-down.
- Front pods: body + integral stub axle with an axle-end insert bore;
  printed INBOARD-face-down so the axle rises axis-vertical (the
  audit caught the outboard-face-down idea standing on the axle tip).

The current inventory includes every registered production solid plus the
optional D034 lid skin. The validator remains the authority for connectivity,
registered keepouts, family-aware mass/CG, bed fit, and zero-support geometry.

Run from the repo root:
    .venv-cad/bin/python cad/python/robot_body_v2.py
Exports land under cad/exports/v2/ (gitignored).
"""

from __future__ import annotations

import math
import sys
from pathlib import Path

sys.path.insert(0, str(Path(__file__).parent))

import robot_body_v2_inventory as inv  # noqa: E402
from build123d import (  # noqa: E402
    Align, Axis, Box, Cylinder, Pos, Rot, Text,
    extrude, fillet, offset, Kind,
    export_step, export_stl,
)

P = inv.P
EXPORT_DIR = Path(__file__).resolve().parents[2] / "cad" / "exports" / "v2"

CORNER_R = P.body_corner_radius            # 25
ROLLOVER_R = P.body_edge_radius            # 12
WALL = inv.WALL                            # 3.2
TRAY_Z0 = inv.TRAY_TOP - P.tray_thickness  # 41
LID_RECESS = 4.0
LID_LEDGE = 6.0
LID_CLEAR = 0.25
ARCH_R = P.wheel_radius + 4.0              # 47: tire-following arch opening
ARCH_BAND = (94.0, 112.0)                  # Y band the arch clears (to just past the wall)
BUMPER_H = P.bumper_height                 # 28
BUMPER_Z0 = 29.0
BUMPER_WALL = 2.5

# Printed-only pan interface (D025/D026).  The collar is fixed to the lid by
# three captive bayonet lugs; the neck journal turns inside it.  These values
# are shared by the lid cuts, the production solids, and the validator.
PAN_JOURNAL_R = 19.80
PAN_JOURNAL_CLEARANCE = 0.35                 # radial, proof-gated
PAN_COLLAR_BORE_R = PAN_JOURNAL_R + PAN_JOURNAL_CLEARANCE
PAN_THRUST_R = 24.0
PAN_COLLAR_R = 30.0
PAN_BAYONET_LUG_R = 28.2
PAN_BAYONET_ANGLES = (90.0, 210.0, 330.0)
PAN_LIMIT_DEG = 60.0
PAN_STOP_STATION_DEG = 72.0
TILT_LIMIT_DEG = 20.0
TILT_HARD_STOP_DEG = 30.0

# Printed ARM-CAPTURE CRADLE (replaces the exact Hitec R-ML24 aluminum horn,
# which has no US quantity-one source, and with it the four M2 link screws —
# the only non-M3 fasteners).  A generic single-arm 24T horn (the arm shipped
# in the D85MG bag qualifies) is retained on the spline by its own arm screw;
# its blade seats in a close-fitting printed slot.  Drive torque is carried by
# the slot walls bearing on the arm flanks, never by screws through the horn's
# link holes.  All four values are PROVISIONAL pending delivered-part
# measurement of the actual bag arm.
ARM_LEN_MIN, ARM_LEN_MAX = 18.0, 27.0   # accepted arm length from spline center
ARM_SLOT_W = 4.6                        # slot width: accepts arm width 4.0 +0.6/-0
ARM_THK_MIN, ARM_THK_MAX = 1.8, 2.6     # accepted blade thickness band
ARM_THK_NOM = 2.5                       # nominal bag-arm blade (shim-rib datum)
ARM_HUB_CLEAR_R = 6.0                   # hub boss + arm-screw head relief radius


def rounded_slab(length, width, height, radius, z0):
    """Vertical-edge-filleted box with its base at z0."""
    b = Box(length, width, height)
    b = fillet(b.edges().filter_by(Axis.Z), radius)
    return Pos(0, 0, z0 + height / 2) * b


def material_mark(label: str, size: float = 4.0, depth: float = 0.35):
    """Small hidden-face family mark for fixed-material parts."""
    return extrude(Text(label, font_size=size, align=(Align.CENTER, Align.CENTER)), amount=depth)
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

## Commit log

2026-07-12 Add initial CAD body concept for Codex Rover Bean (#1)
    * Add initial CAD body concept
    * Add finished body concept art
    * Add finished exploded concept art
    * Trying to better match the concept art
    * Add Blender body concept refinement
    [base_tray.scad, battery_cradle.scad, bumper_carrier.scad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]
2026-07-12 Add printable robot body and illustrated assembly guide (#2)
    * Latest robot body renderings
    * Add plan for beige body
    * Add script for beige body
    * Delete a bunch of old models/renders
    * Delete initial plans for 3d modeling
    * Delete more
    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
    [base_tray.scad, battery_cradle.scad, bumper_carrier.scad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]
2026-07-16 Add printed-only body simplification plan (D025-D028) (#3)
    Plan the v2 body rework: eliminate all purchased metal structure
    (brackets, standoffs, spacers, shoulder bolts, bearings, hubs) in favor
    of printed geometry, with M3 x 5.7 heat-set inserts and M3 x 8 screws as
    the only separately purchased body fasteners. Shrink the footprint to a
    238 x 220 x 133 one-piece shell/tray/lid, cap the printed inventory at
    40 parts with a zero-support printing target, and record the four
    decisions (D025-D028) plus the four-round review history that produced
    the current box-level layout (v5.1).
    The packing screen (cad/python/packing_study_printed_only.py) closes at
    box level with verified model datums and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
2026-07-16 Add v2 inventory, BREP model skeleton, and inventory-driven validator (#4)
    Phase 2 of the printed-only rework (D025-D028). Three new modules under
    cad/python plus the packing screen refactored into a pure check engine:
    - robot_body_v2_inventory.py: the registered inventory — 43 envelopes,
    each recording its Params/helper basis or ESTIMATE status, the
    verified datums defined once, the 2 mm margin policy, and the D028
    printed-part registry (46 draft instances, 40 after owed merges).
    - robot_body_v2.py: 18 build123d solids in the v5.1 layout — one-piece
    tray (battery cradle, Pico bosses, six molded-in switch pockets),
    shell (offset-shelled rollover, tire-following circular arches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
    [robot_body_v2.py, robot_body_v2_inventory.py]
2026-07-16 Eliminate estimates, execute part merges, add the D026 fastener system (#5)
    Second Phase 2 slice. The inventory reaches zero ESTIMATE envelopes
    (neck_drop derives from the verified pan_servo_fit bbox; the head roof
    keepout becomes the computed pan-sweep of the v2 head; the Pi/Pico
    service volumes are declared cable/tool specs), and all six owed part
    merges are executed, landing the D028 registry at exactly 40 printed
    parts with zero owed — the E-stop backing collar is now a lid-integrated
    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
2026-07-16 Encode harness routes, connector sweeps, and the mass/CG budget (#6)
    Third Phase 2/3 slice: the remaining gate-check classes become
    registered envelopes and validator checks, all green in --gate mode.
    - Harness route volumes: motor leads (saddle to the switched-power
    rail, mirrored), speaker/amp feed into the signal rail, and the
    camera FPC path — east of the AI-HAT reserve, crossing north of the
    pan servo, entering the neck bore with every corner inside the r14
    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
2026-07-16 Model the deck solid with integrated harness ribs and fuse pocket (#7)
    Completes geometry for every major structural part (21 solids). The
    removable deck models its three registered plate segments (riser notch
    and trimmed NW region as gaps), harness ribs flanking the two wire
    channels — the D028 merge that made the v1 harness rails deck geometry —
    a fuse-block pocket lip, and counterbored tower-joint holes holding the
    3.2 mm clamp stack. It prints top-face-down so ribs and lips build
    upward, support-free.
    The validator gains solid-ownership semantics: a solid may fill its own
    registered envelopes (the deck fills the deck-plate boxes) without
    tripping the interference check, while remain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
    [robot_body_v2.py, robot_body_v2_inventory.py]
2026-07-16 Add the v2 coupon program and print-ready export chain (#8)
    Calibration before large parts, per the repo's build order:
    robot_body_v2_coupons.py exports eleven coupons with a manifest —
    M3 insert fit, the D026 standard joint as a two-piece flange/boss
    test, the 4 mm D-bore torque coupon (2x stall gate), the printed
    axle + bushing wear pair, snap and bayonet interface pairs, the
    molded switch-pocket slice at the 0.4/2.0/2.4 bumper values, the
    scaled TPU tire-fit pair, and the Pico capture-clamp pattern.
    robot_body_v2_print.py rotates every primary solid into its declared
    print pose (the same PRINT_UP vectors the D028 audit runs against),
    grounds it, re-verifies bed fit in-pose, and writes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
2026-07-16 Model the remaining registered parts; merge the E-stop panel into the lid (#9)
    Every printed part in the D028 registry now has a solid (31 designs;
    the print manifest's pending list is empty): mic cradle, speaker/ToF/
    Pico clamp bars with their shell, lid, and tray insert bosses, the TPU
    battery pad frame (the tray pads drop to 2 mm so the pack datum is
    unchanged), the head yoke with integrated horn-adapter arms, the tilt
    shoulder bushing, both lime diffuser bars, and the printed washer.
    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
2026-07-16 v2 render pipeline and first review renders (#10)
    * Model the remaining registered parts; merge the E-stop panel into the lid
    The separate E-stop mount panel merges away: the v2 lid is itself a
    removable 4 mm panel inside the IDEC's 0.8-6 mm clamp range, and the
    integrated collar bor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
2026-07-17 Generate the v2 assembly guide from the live manifests (#11)
    docs/generate_assembly_guide_v2.py builds the 8-page landscape guide
    from the print manifest, coupon manifest, and the inventory's joint and
    fastener registries, so the guide cannot drift from the model: cover
    with the hero render and spec block, safety page, the single-SKU
    fastener system with the full 13-family joint table, coupons-first
    page, the two-page support-free print inventory, the ten-step one-hex-
    key assembly order with per-step joint references, and the service
    view with release gates (explicitly: nothing authorizes powered
    motion).
    Pages verified by rasterizing with pypdfium2 from the project venv
    (poppler is not in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
    [generate_assembly_guide_v2.py]
2026-07-17 Add the v2 Bambu Studio project and the picture-first assembly guide (#12)
    cad/bambu/generate_bambu_project_v2.py adapts the v2 print chain into
    the proven v1 Bambu machinery: part designs expand into per-instance
    staged STLs, plate-filling parts (tray, shell, bumper halves) take solo
    centered plates, and the result round-trips through Bambu Studio. The
    tracked codex_robot_body_v2_p1s.3mf carries 43 instances on 13 plates
    in 6 filament groups (v1 needed 26 plates), with the plates JSON and a
    contact sheet.
    Building the 3MF caught design error #13: three parts were disconnected
    solids (the shell's corner lugs floated where the tire-following arch
    openings wrap the corners — the lugs move t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
    [codex_robot_body_v2_p1s.3mf]
2026-07-17 Rebuild the assembly guide as a 32-page HTML-to-PDF builder's book (#13)
    The guide generator now authors fixed-size HTML pages (11 x 8.5
    landscape, product-manual styling with full CSS layout) and prints them
    to PDF with headless Chrome, replacing the ReportLab layout. Content
    still generates from the live artifacts — printed-part registry, joint
    and fastener tallies, the Bambu plate manifest, and the coupon
    manifest — plus authored copy written for a ten-year-old who has never
    seen the project.
    New coverage requested for this edition: a complete shopping chapter
    (filament weights per color from the actual solid volumes, the two
    fastener SKUs, the full electronics list with kid explanat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
    [generate_assembly_guide_v2.py]
2026-07-17 Polish the builder's book through five adversarial review rounds (#14)
    Iterated the v2 assembly guide against repeated LEGO-instruction-standard
    reviews until it passed final acceptance:
    - Register the head tilt-pivot joint so the fastener system is truly
    41 screws + 41 inserts everywhere (validator gate: PASS, 0 warnings)
    - Fix a real Bambu generator bug: per-side pods/bumpers double-counted
    on plates; print 6 washers (2 used + spares, now said in print chapter
    and step 6); rear panel joins the charcoal group; washer set counts
    once against the 40-part budget
    - Rebuild the assembly sequence: switches click in before bumpers wrap,
    front ToF boards seat before the face panel, the l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
    [codex_robot_body_v2_p1s.3mf]
2026-07-17 Rebuild the builder's book as a retail-grade manual without grown-up callouts (#15)
    Brian's direction (D029): keep the book child-followable, drop every
    grown-up callout, and polish the whole kit toward a professionally
    produced product.
    Content: the GROWN-UP STEP banner, red step numbers, cover badge,
    grown-up tool labels, coupon notes, and wiring-chapter framing are all
    gone. Safety content stays as plain instructions and checklists.
    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
2026-07-17 Overhaul the builder's book renders and fix the review findings (#17)
    A full page-by-page review of the v2 builder's book, step renders, and
    model (docs/guide-v2-improvement-notes.md) surfaced real bugs and a set
    of clarity problems; this lands the fixes end to end.
    Model fixes:
    - The lime eye bar could not reach the eyes (30 mm bar vs slots 80 mm
    apart). It is now a 98 mm goalpost: a plate behind each eye slot,
    bridged above the camera aperture so nothing crosses the lens.
    - Every tire gets a 7.2 mm radial tread port so the rear rim clamp screw
    stays reachable with the tire mounted (it was buried before).
    - Status-bar pads gain real 0.6 mm snap clearance.
    Guide content fixes (robot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
    [codex_robot_body_v2_p1s.3mf]
2026-07-17 Fix both wheel retentions: deep rear screw well, real front cap washer (#19)
    Brian's question about the step-4 render (does the insert really go in
    the tire?) exposed that neither wheel retention actually worked:
    - Rear: the clamp-screw insert bore opened at the rim surface, so the
    single-SKU M3 x 8 threaded into it ended ~12 mm short of the motor
    shaft — the screw clamped nothing. The bore is now a stepped well:
    a 7.4 mm head/tool channel from the rim, the 4.6 mm insert seat deep
    in the wheel, and tip clearance ending 0.3 mm past the shaft flat, so
    the screw tip presses the flat snug. The insert drops down the well
    and is pressed home with the iron tip, tire still off. All th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
    [codex_robot_body_v2_p1s.3mf]
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2026-07-17 Add hybrid PLA and PETG material pipeline (#22)
    [codex_robot_body_v2_p1s.3mf]
2026-07-18 Complete v2 head mechanics and guide review fixes (#23)
    [codex_robot_body_v2_p1s.3mf]
2026-07-18 Polish v2 guide and ship coupon project (#24)
    [codex_robot_body_v2_coupons_p1s.3mf]
2026-07-18 Add unpowered safety commissioning fixture (#27)
    [commissioning_fixture_v1.scad, commissioning_fixture_v1_data.scad]
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2026-07-18 Harden v2 beginner assembly release (#30)
    [codex_robot_body_v2_coupons_p1s.3mf, codex_robot_body_v2_p1s.3mf]
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2026-07-19 Make the v2 guide buildable by a cold reader and cut release prototype.3 (#32)
    A from-scratch buildability review found a new user gets stopped before
    printing: the QR target had no downloads, blocked BOM rows read as
    shopping rows, and the wiring chapter presented itself as an executable
    step. Fixes, shipped as Builder Release v2.0.0-prototype.3:
    - Point RELEASE_URL at the GitHub release page (downloadable 3MFs + PDF)
    and say where to download the print projects in Chapter 2 and both QR
    captions.
    - Mark the R-ML24 horns, hardware pack, and D36V50F6 rows DO NOT BUY YET
    with qty 0-for-now; add red SOURCING GATE banners to steps 18-19 (via
    STEP_NOTES so arrow numbering is untouched) a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
    [builder_release_catalog_v2.py, builder_release_v2.py, generate_assembly_guide_v2.py]
2026-07-19 Finish the book: bring-up chapter, mirrored-badge fix, honest renders, audited arrows (#33)
    Chapter 5 now carries a builder from the finished dry body to a running
    brain: the shipped robotd simulator + supervision dashboard on any
    Mac/Linux (with a real, script-captured screenshot), the condensed Pi 5
    appliance install, and the resident copilot's seat — its full Pi
    authority, the firmware/physical floor it can never cross, and a
    replayable --source agent robotctl session. Release ID bumps to
    v2.0.0-prototype.4; the release index gains the dashboard and
    provisioning-guide artifacts plus an optional candidate-PLA row.
    A five-reviewer audit (four page readers + a computed consistency pass)
    d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
    [builder_release_catalog_v2.py, builder_release_v2.py, generate_assembly_guide_v2.py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]
2026-07-19 Rename the v2 qualification pieces: coupons are now proofs (D038) (#34)
    Each small qualification piece proves exactly one v2 design contract, so
    the set is now called proofs — print and pass these proofs. Approved
    full-v2 scope:
    - git mv: robot_body_v2_proofs.py, generate_bambu_proofs_v2.py,
    codex_robot_body_v2_proofs_p1s.3mf (+ plates JSON + contact PNG),
    docs/cad-proofs.md.
    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
    [codex_robot_body_v2_coupons_p1s.3mf, codex_robot_body_v2_proofs_p1s.3mf]
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2026-08-12 Make the build kind and ship the interactive builder's site (D040-D052) (#36)
    * Add Pi-side head trim and the robot-hello wake-up script
    --head-trim-pan-cdeg/--head-trim-tilt-cdeg (clamped to one 24T spline
    tooth, +/-800 cdeg) shift HEAD setpoints before framing so horns can land
    on the nearest spline tooth with no servo tester; the blackbox journals
    raw and trimmed values and status exposes the active trim. robot-hello
    runs the gentle narrated head sweep (source="hello") against a running
    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
    [codex_robot_body_v2_p1s.3mf, codex_robot_body_v2_proofs_p1s.3mf]
2026-08-13 Simplify the electrical program: 5V shared rail, named candidates, owning != installing (D053-D060) (#37)
    Answering 'how much does this robot actually need to do': the head
    servos move to the 5V rail as their own fused branch (D053) — the
    separate 6V regulator, its purchase gate, and its bench rail cease to
    exist (the dual-footprint bay stays as a reserved spare; harness H2
    retargets PWR-10/11/12; plan C5 folds the shared-rail transient proof
    into C006/C022). The relay driver and Pico reset gates now name their
    exact candidates — the fixture's Adafruit 5648 (D054) and a seventh
    Omron D2HW behind a printed guard (D055) — each one bench session from
    clearing. Owning splits from installin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
    [builder_release_catalog_v2.py, builder_release_v2.py, generate_assembly_guide_v2.py]

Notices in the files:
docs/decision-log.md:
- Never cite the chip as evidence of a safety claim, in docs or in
